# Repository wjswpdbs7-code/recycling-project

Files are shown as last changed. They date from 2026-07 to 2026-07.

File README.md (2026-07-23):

# ♻️ 가정용 분리수거 자동분류기 (Recycling Auto-Sorter)

> 쓰레기를 올리면 **AI가 판별하고 기계가 알아서 분류**하는 온디바이스 엣지 AI 시스템.
> HRD 직업훈련 최종 프로젝트 (12주) — YOLO11 · TensorRT · Jetson Nano · Raspberry Pi Pico 2 W

```
[투입] → 초음파 감지 → 3초 안정화 → C920 10프레임 촬영(1초)
      → TensorRT 판정(GPU 50ms/장) → ★10프레임 다수결★
      → 회전판 정렬(종이 0°/플라스틱 90°/비닐 180°) → 투입구 개방 → 낙하
      → 판별불가·비대상은 문을 열지 않고 리턴 (오분배 원천 차단)
```

## 핵심 수치

| 지표 | 값 |
|---|---|
| 학습 데이터 | AI Hub 생활폐기물 102,271장 / 17클래스 / 활용률 100% |
| 모델 | YOLO11n (2.6M 파라미터, 5.3MB) |
| 공식 Validation | mAP50 **0.912** (품목 병합 시 91~98%) |
| 학습 비용 | 약 **$10** (RunPod A40) |
| 엣지 추론 | **49.6ms/프레임** (Jetson Nano, TensorRT FP16) |
| 실물 테스트 | 오분배 **0건** (애매하면 리턴하는 안전 설계) |
| 자동 시작 | 전원 인가 → **약 40초 후 무인 가동** (systemd) |

## 시스템 구성

- **Jetson Nano** — 두뇌: C920 촬영, TensorRT 추론, 다수결 판정, 웹 모니터링(MJPEG)
- **Pico 2 W** — 손발: 초음파 감지·서보 2개(투입구/회전판)·LCD 상태표시, 상태머신 펌웨어(C)
- **노트북** — 개발·모니터링 전용 (분리해도 기계는 자립 동작)

## 저장소 구조

| 경로 | 내용 |
|---|---|
| `docs/` | **전체 문서** — 진행일지·설계서·클래스 설계·학습 보고서·배선 가이드·제작도·[포트폴리오 기록](docs/05_포트폴리오_기록.md) |
| `docs/img/` | 학습 곡선, confusion matrix, 실물 테스트 캡처, CAD 렌더, 성능 차트 |
| `models/` | 학습 완료 가중치 (.pt) + ONNX 변환본 |
| `training/` | AI Hub JSON→YOLO 변환기, 학습 결과 로그·곡선 (원본 데이터셋 20GB는 제외) |
| `inference/` | 판정·데모 코드 — Jetson 브리지, 노트북 브리지, 수집 도구, 스트리밍 |
| `pico_sonar_test/` | **최종 구동부 펌웨어** (상태머신: 감지→분배→재무장, LCD 자가복구) |
| `pico_*` | 개발 과정의 테스트·진단 펌웨어들 (초음파/LCD/서보 진단 도구 포함) |
| `cad/` | OpenSCAD 파라메트릭 3D 설계 (검증식 내장) |

## 문서 읽는 순서 (발표자료·기술서 제작용)

1. [`docs/05_포트폴리오_기록.md`](docs/05_포트폴리오_기록.md) — **의사결정 서사·시행착오·수치 총정리** (발표의 뼈대)
2. [`docs/00_진행일지.md`](docs/00_진행일지.md) — 일자별 타임라인
3. [`docs/03_학습_보고서.md`](docs/03_학습_보고서.md) — 학습 상세 + 실물 테스트 분석
4. [`docs/02_클래스_설계.md`](docs/02_클래스_설계.md) / [`docs/06_프로토타입_제작도.md`](docs/06_프로토타입_제작도.md) — 설계 근거

## 재현 방법 (요약)

```bash
# 1) 데이터: AI Hub 71385 실내형분류기 다운로드(국내 IP) 후 변환
python3 training/convert_aihub_to_yolo.py <이미지경로> <라벨경로> <출력> 17

# 2) 학습 (RunPod A40 기준)
yolo detect train model=yolo11n.pt data=data.yaml epochs=60 imgsz=640 batch=128 workers=8

# 3) Jetson 배포
yolo export model=best.pt format=onnx opset=12
/usr/src/tensorrt/bin/trtexec --onnx=best.onnx --saveEngine=runB17.engine --fp16

# 4) 실행 (Jetson): inference/jetson_bridge.py — systemd 서비스로 자동 시작
```

※ 데이터셋(20GB)·API 키(.env.local)는 저장소에 포함하지 않음.

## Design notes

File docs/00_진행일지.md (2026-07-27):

# 진행 일지 — 가정용 분리수거 자동분류기

> 목적: 사용자와 AI가 프로젝트 흐름을 빠르게 파악하기 위한 일자별 기록.
> 규칙: 의미 있는 작업·결정이 있을 때마다 그 날짜에 추가한다. 형식은 "한 일 / 결정 / 산출물" 3줄 구조를 기본으로.

---

## 2026-07-15 (화)

- **한 일**: 프로젝트 설계서 v0.1 작성 (6클래스, 캐러셀 방식, 저가형/표준형 티어). Pico 2 W + 서보 2개 + 버튼 테스트 (MicroPython)
- **결정**: 분배 기구는 회전 캐러셀 방식 채택
- **산출물**: `docs/01_설계서.md`(당시 루트), `servo_button_test.py`

## 2026-07-16 (수)

- **한 일**:
  - 서보+버튼 테스트를 C(Pico SDK)로 변환, WSL에 빌드 환경 구축(ARM 툴체인·SDK, sudo 없이) → `servo_button.uf2` 빌드 성공
  - 언어 전략 확정: Python(AI·서비스·대시보드) + C(MCU 실시간 제어)
  - 아파트 규모 논의 → 벌크 싱귤레이션은 선별장 영역, 투입구 제어(RVM 방식)가 정답. 처리량 계산
  - **클래스 4종 축소 결정** (비닐·종이 제외 → 경질 용기류만): 난이도가 "도전적→검증된 영역"으로
  - 데이터셋 조사(AI Hub 생활폐기물 71385 추천), 사용자가 받은 샘플 105장 분석 — 실내형분류기 파트가 우리 구도와 일치 확인
  - 학습 비용·시간 추정($10~20), 성능 목표 3층(모델/실기기/시스템) 정의
  - **RunPod 파이프라인 검증**: JSON→YOLO 변환기 작성, A40 팟에서 샘플 105장 스모크 학습(mAP50 0.911) 후 팟 종료 — 총 $0.11
  - 아파트 분리배출 규정 조사(투명페트 의무 등), YOLO 필요성 확정(검출=개수 검증 겸용), MCU/NPU 엣지 사양 조사(STM32N6 34FPS 실증), 혼합 쓰레기 싱귤레이터 기구 설계(클리트 컨베이어+리턴 루프, BOM 9~17만원)
- **결정**: 4클래스(투명페트/플라스틱/캔/유리) + 판별불가(비학습·후처리), YOLO11n, RunPod A40급, 실내형분류기 파트만 사용
- **산출물**: `servo_button_c/`, `training/convert_aihub_to_yolo.py`, `models`(스모크 테스트 결과는 `training/results_pipeline_test/`)

## 2026-07-17 (목)

- **한 일**:
  - AI Hub 공식 가이드라인 PDF(53쪽) 분석 → **29종 클래스 코드 공식 매핑표 확보** (페트=투명 무색만 확인)
  - aihubshell + API 키로 B2 파트(86MB) 테스트 다운로드 → 실측: B2는 93%가 오염 배치 → 오염 클래스 필요성 부상
  - 오염 라벨 기준 실물 확인(경계 애매성 발견), 데이터셋 분리 구조(품목×상태 매트릭스) 분석
  - **클래스 설계 탐구 → 9클래스(4품목+품목별오염4+other) 채택** — B2 실측 활용률 4%(4클래스) vs 100%(9클래스). `docs/02_클래스_설계.md` 작성
  - Run A 준비: A40 팟 생성 → **AI Hub 해외 IP 차단 발견** → 국내 로컬 다운로드(16GB) 후 rsync 업로드로 우회 (팟에 rsync 설치 필요했음)
  - 공식 Validation 실내형분류기 12,784장 로컬 확보·분포 분석 (학습 미사용, 최종 평가 전용 원칙 수립)
  - **Run A(4클래스 기준선) 학습 시작** — 실분포 확정: 39,643장/102,271장(38%). 중간 과적합 점검: 이상 없음
- **결정**: 9클래스 설계(당시), 평가는 공식 Validation + B폴더(조명)별 분해, Run B는 배치·worker 최적화 적용
- **산출물**: `docs/02_클래스_설계.md`, `training/aihub_download/`(Training 16GB + Validation 2GB), 변환기 모드 4/8/9

## 2026-07-18 (금)

- **한 일**:
  - **Run A 완료** (80ep, 5.2h): 공식 Validation **mAP50 0.985** (페트 0.991/플라스틱 0.962/캔 0.994/유리 0.991) — 전 클래스 목표(0.95) 통과, 과적합 없음
  - 모델 회수: `models/runA_yolo11n_4cls_best.pt`
  - **최종 클래스 17종으로 상향 확정** (아파트 규정 풀스펙: 클린9+오염8, other 소멸) — "학습은 17종, 추론 병합으로 5칸 시연" 구조. 9클래스 학습은 중복이라 생략
  - **Run B-17 학습 시작** — 1차 시도 OOM(컨테이너 RAM 한도 50GB, worker 24 과다) → worker 8로 재시작, 102,271장/60ep
  - **docs/ 폴더 신설·문서 대정리**: 설계서 v0.2 갱신(폐기된 6종 체계 등 구버전 내용 수정), 학습 보고서+그래프 작성, 인덱스·문서 규칙 수립, 본 진행일지 신설
  - 골판지 프로토타입 계획(서보2+DC1로 3분류 데모), 3D 모델링 방침(OpenSCAD 코드 CAD) 수립
- **결정**: E안 17클래스 최종 채택, 문서는 docs/에만 작성·구버전은 수정(중복 금지)
- **산출물**: `docs/` 전체 구조, `docs/03_학습_보고서.md`, 변환기 모드 17
- (오후) 웹캠 실물 테스트 환경 구축(`inference/watch_and_predict.py`, 촬영→즉시판정) —
  스프라이트병→플라스틱 오분류로 도메인 갭 실증. 복수 물체 카운트 동작 확인
- (오후) 3D 모델 v0.2→v1.0 재설계: 수직 낙하+캐러셀 정렬 방식 확정(깔때기 기각),
  과설계 제거(서보1 트랩도어·게이트/리턴 삭제), MDF 판재 구조, 검증 echo 내장(화각·낙하고·2L수용)
- **Run B-17 완료** (60ep, 총 ~7h·OOM 2회 극복): 공식 Validation 17클래스 mAP50 0.912.
  confusion matrix 분석 → 오류의 대부분이 "같은 품목 클린↔오염 혼동", 품목 병합 시 Run A급.
  **채택: Run B-17 단일 모델 + 품목병합 분배 + 오염 임계값 후처리.** 모델 회수·팟 종료(잔여 0)
- **비용 실적**: 전체 학습 캠페인 누적 약 $10 (예산 $10~20 내 완료)
- (저녁) 추론 데모를 Run B-17 + 채택 후처리(품목병합·오염임계·배출코칭)로 업그레이드 —
  Run A가 오인했던 종이컵을 정확 인식하며 복수 투입 판정 성공
- (저녁) **3D 모델 심층 개선 세션**: WSL 헤드리스 OpenSCAD 구축(AppImage) → AI가 렌더를
  직접 보며 평가-개선 3사이클. 렌더 검증으로 실결함 2건 발견·수정:
  ① 외닫이 트랩도어 개방 궤적이 수거함 관통(→ 양문 필수로 번복, 검증4 추가)
  ② 유리 낙하고 30mm vs 문짝 스윙 106mm 상충(→ 스테이지 +120mm로 양립)
  깔때기 목을 문열림 궤적 포함하게 재설계. 코드 내장 검증 4종 전부 통과.
  외장(디스플레이·투입구 베젤·회수도어·받침발)·기구 사실화(지지롤러·GT2벨트·경첩) 추가.
  렌더 3종 docs/img/cad_v11_*.png 보관
- (밤) **웹캠 실물 테스트 세션 2차** (사용자 직접, 12장, 검은 천 배경 채택): 투명 트레이→플라스틱 80% 정답,
  키친타올→종이 76% 배출 코칭 성공. 잘못된 수거함 분배 0건(애매 케이스 전원 판별불가행)

## 2026-07-19 (토)

- **한 일**: 분류테스트 12장 결과·원인 분석
  - 오류 3유형 확인: ① 검은 천 위 유령 검출(빈 배경에 glass 75% — 프레임 가장자리·어두운 주름 영역) ② 깨끗한 세제통→plastic_dirty 85%(그래픽 라벨을 오염으로 오인) + 투명 펌프캡→battery 59%(소형 원통 형태) ③ 물티슈(비닐)→paper 67%(연포장 인쇄면이 종이와 유사)
  - 근본 원인 3계층으로 정리: 도메인 갭(조명·블러·배경) / 경량 모델의 형태·색 프라이어 의존 / 후처리에 박스 위치·크기 검증 부재(유령 1개가 복수투입 오판으로 승격)
- (밤) 회색 무광 배경판으로 교체 후 추가 테스트 — 유령 박스 0건(배경 개선 효과 확인).
  단 **미학습 물체(OOD) 고신뢰 오분류 발견**: 딱풀→paper 75%(무광 원통+인쇄 라벨 프라이어),
  접착제 병→can 92%(스프레이캔 실루엣). 폐쇄형 검출기의 구조적 한계로 CONF_TH 안전망 무력화 —
  테스트 통틀어 첫 "잘못된 분배" 사례. 물티슈 팩도 paper 94%로 재오분류(검은 천 67%→회색 94%) —
  **환경 개선은 유령 검출은 제거하지만 학습 분포 밖 물체는 "더 확신 있게" 틀리게 함** →
  남은 오류는 환경이 아니라 데이터(fine-tuning)로만 해결 가능함을 실증
- **결정**: fine-tuning 촬영 목록에 그래픽 라벨 용기·물티슈류 연포장·소형 캡 필수 포함 + **비대상 물체(문구류 등)를 라벨 없는 네거티브 샘플로 추가**. 시연 물품은 학습 도메인(재활용 배출품)으로 구성. 데모 스크립트에 ROI+최소 박스 크기 필터 추가 예정
- **산출물**: 분류테스트/결과/ 판독 14건, `docs/03_학습_보고서.md` 실물 테스트 절 추가

## 2026-07-28 (월)

- **한 일**: **회고형 포트폴리오 PDF 제작** (HRD서류 폴더) — 성과 부각 대신 자체 피드백/아쉬운 점 중심 4페이지.
  구성: 요약(사실 수치만) → 유효했던 선택 5 → 아쉬운 점 5(모터 미검토/싱귤레이터 미착수/골판지·CAD 단절/
  파인튜닝 게이트 미달/분배 검증 미완 — 각각 "아쉬움→당시 상황→배운 것" 구조) → 트러블슈팅 6건 표 →
  후속 과제 6건(피드백과 1:1 대응, 진행 예정 명시). WeasyPrint(HTML→PDF)로 생성
- **이미지 중심 개정판**: 사용자 요청으로 `포트폴리오 모음/분리수거_자동분류기_포트폴리오.pdf`로 재제작 —
  docs/img 22종(실물 사진·회로도·학습곡선·혼동행렬·ft1 실물판정 7종 그리드·트러블슈팅 증상 사진·CAD)을
  각 절에 배치한 7페이지 판 (텍스트 서사는 동일, WeasyPrint)
- **산출물**: `포트폴리오 모음/분리수거_자동분류기_포트폴리오.pdf` (HRD서류 폴더 — repo 외부)

## 2026-07-27 (일)

- **한 일**: **발표자료 3차 수정본 작성** (HRD서류 폴더, 원본과 별도 저장) — 성과 강조형에서 **자체 평가형으로 전면 개편**.
  - 최종 목표를 "싱귤레이터(1개씩 분리) → 엣지 AI 판별 → 회전판 정렬 → 투입구 개방" 4단계로 명시하고,
    현재 구현 범위는 **3종 분류(서보 한계) + 투입구 카메라 엣지 분석까지**임을 개요부터 밝힘
  - 한계점 슬라이드 → **"자체 피드백 및 후속 과제"**로 개편: 기획 단계 하드웨어 선택 미흡(SG90 토크·가동각 미검토
    → 3칸 제한, 싱귤레이터 미착수, 골판지 수작업 개입) vs 유효했던 선택(17종 학습·병합, 파인튜닝+사전 게이트,
    엣지 TensorRT, 저비용 센서) 구분 + 후속 과제(싱귤레이터 설계 / 구동계 재선정 / MDF·3D프린트 재질 개선) 1:1 대응
  - **거짓 없는 수치·서사로 교정**: 실제 제작에 활용 못한 OpenSCAD CAD 강조 제거, 추론 속도를 채택 모델 기준
    51.5ms로 갱신, ft1 "게이트 0.892 미달(0.880) → 보류 → 실물 7/7 재검증 후 채택" 2단계 의사결정 명시
- **결정**: 발표 톤 = 좋았던 점/아쉬운 점/발전 방향 균형 서술, 성과 과시·미활용 작업 강조 배제
- **Wokwi 회로도 최종 설계 반영**: 구버전(`pico_sorter/wokwi`, 서보2개 4칸 v1)을 최종 펌웨어 위치
  `pico_sonar_test/wokwi/`로 이전·전면 갱신 — 서보1 도어 GP0(90/180)·서보2 회전판 GP1(0/90/180 3칸),
  HC-SR04 GP16/17(1k/2k 분압), LCD1602 I2C GP4/5, **서보 전원 별도(VCC 심볼)+GND 공통** 반영.
  main.py도 실물 C 상태머신(ARMED→SETTLING 3s→DETECT→WAITCMD→COOLDOWN)과 동일하게 재작성
- **프로젝트 기술서 작성**: 2차 기술서(hwp) 양식 구조를 그대로 재현해 최종 프로젝트 기술서 docx 생성
  (작성자 전제윤, 팀원 김도경·박시영 역할 분담 기재. 수행목표에 최종 4단계 목표 vs 현재 구현 범위 구분,
  상세 내용 5절: 본학습/파인튜닝·게이트/엣지 추론/기구 제어/한계·후속과제, 이미지 7종 삽입 — 회로도·학습곡선·혼동행렬·실물판정·시연)
- **발표문 작성 + 배경 서사 개편**: 슬라이드 1~11 발표문(약 10분) 작성. 이후 2·3번 슬라이드와 발표문을
  **편의성 중심 서사**(사람이 분류하지 않는 시스템을 아파트 단지 재활용장 단위로)로 재구성
- **산출물**: `발표자료_3차 수정본.pptx`, `발표문_1조_분리수거_자동분류기.docx`, `최종_1조_프로젝트_기술서_분리수거_자동분류기.docx` (HRD서류 폴더 — repo 외부),
  `pico_sonar_test/wokwi/{diagram.json,main.py}`

## 2026-07-24 (목)

- **한 일**:
  - **ft1 Jetson 배포 완료**: ONNX(opset12) 변환 → 전송 → TensorRT FP16 엔진 빌드(`runB17_ft1.engine`,
    추론 **51.5ms/프레임** — 기존 49.6ms와 동급) → `jetson_infer.py` 엔진 전환 → `sorter.service` 재시작.
    기동 확인: 엔진 로드·시리얼(/dev/ttyACM0)·웹모니터(8081) 정상. 기존 `runB17.engine`은 롤백용 보존
  - **웹모니터 영상 미표시 트러블슈팅**: 원인은 카메라가 아니라 **기동 순서** — 브리지 시작 시점에
    `/dev/video0` 미존재(uvcvideo가 13분 뒤 등록, dmesg로 확인) → 카메라 열기 1회 실패 후 그대로 운용,
    감지 시 프레임 0장으로 무조건 REJECT. 재시작으로 즉시 해결 + **자동 복구 패치**(열기 재시도 30회,
    운용 중 6초 연속 실패 시 재연결, 최종 실패 시 종료→systemd 재기동)
  - **ft1 실물 검증 7/7 전원 정답** (`docs/img/ft1_test_*.png`, 신뢰도 94~99%):
    종이뭉치 paper 98 / 종이컵 paper_pack 99 / **본드병 plastic 97(기존 can 92% 오분류 해결)** /
    돔뚜껑 pet 98 / 찌그러진 페트병 pet 94 / **투명 지퍼백 vinyl 97(기존 전 프레임 미검출 해결)** /
    검정 비닐 vinyl 98 — 자체 val 0.995가 실물에서 재현됨
- **결정**: **ft1 채택 확정** — 파인튜닝 목적(OOD 물체·투명 비닐 사각지대)이 실물로 입증됨.
  일반화 −3.2%p는 시연 범위에서 무영향
- **산출물**: `models/runB17_ft1_best.onnx`, Jetson `runB17_ft1.engine`, `inference/jetson_infer.py`(엔진 전환),
  `inference/jetson_bridge.py`(카메라 자동 복구), `docs/img/ft1_test_*` 7종

## 2026-07-22 (화) ~ 07-23 (수)

- **한 일**:
  - **골판지 프로토타입 기구 조립·캘리브레이션**: 투입구=서보1(물리핀1, 닫힘90°/열림180° 실측),
    회전판=서보2(물리핀2). FSR 검토 후 초음파로 회귀. 십자 프레임(팔 90° 간격) 제작
  - **3칸 분배 체계 확정**: 0°=종이(+종이팩) / 90°=플라스틱(+투명페트) / 180°=비닐, 그 외 REJECT 리턴.
    십자 프레임과 SG90 180° 한계에 정합 (SG90은 270° 불가 — 소프트웨어 아닌 내부 기구 한계)
  - **펌웨어 상태머신 완성** (`pico_sonar_test`): 감지→3초 안정화→DETECT→분석대기(초음파 무시)→
    SORT(회전판→문 개폐)→쿨다운→재무장. LCD 상태 표시 전체(READY/DETECTED/ANALYZING/RESULT/COMPLETE/리턴사유별)
  - **10프레임 다수결 판정 도입**: 1초간 10프레임 → 프레임별 판정 → 최다 득표 채택 (시간축 앙상블)
  - **노트북 브리지** (`bridge.py`, 8092): 브라우저 한 페이지에서 웹캠+Web Serial(COM5)+판정 —
    실시간 미리보기·프레임별 오버레이·감지 로그·C920 자동 선택
  - **fine-tuning 수집 도구** (`collect_data.py`, 8091): 숫자키=클래스, 위치는 모델 프리라벨(클래스무관
    최고신뢰 박스)·클래스는 사람 — 반자동 라벨링. 오버레이 미리보기·x키 실행취소
  - **Jetson 전자동 브리지 완성·검증** (`jetson_bridge.py`): DETECT→10프레임(GPU, 1초!)→다수결→SORT/REJECT.
    노트북 모니터링 웹(8081, MJPEG+로그) 내장. **REJECT 경로 실기 검증** (투명 지퍼백 → 전 프레임 미검출 →
    리턴 — 안전망 정상. 지퍼백은 비닐 fine-tuning 목록에 추가)
  - **모델 동일성 3중 검증**: ONNX md5 일치 / 17클래스 매핑 완전 동일 / 동일 이미지 교차추론 (can 0.479 vs 0.441,
    fp16 오차 정상 범위)
  - **systemd 자동 시작 등록·재부팅 실증**: 전원만 꽂으면 ~40초 후 분류기 자동 가동 (sorter.service, Restart=always)
  - 트러블슈팅: Jetson 시리얼 권한(dialout 그룹), 원격 pkill 자기종료 함정(브래킷 패턴), 발열 실측(부하 중 GPU 39°C)
  - **운용 조정**: 신뢰도 리턴 기준 0.50→**0.40** 완화(4개 판정 코드 일괄, 리턴율 개선 목적).
    LCD 개선 2건 — 대기화면에 **마지막 판정 결과 유지**(`LAST: PAPER`), 서보 노이즈로 인한 글자 깨짐에
    **자가 복구**(사이클 복귀·30초마다 재초기화). **Jetson에서 Pico 직접 굽기** 확립(부트로더 드라이브 원격 마운트 —
    케이블 이동 불필요). 모델 동일성 3중 검증(ONNX md5·매핑·교차추론), 노트북 분리 자립 운용 확인
  - **시연 영상 4편 확보** (`docs/img/demo_cycle_*.mp4`, 총 38초): 조립 완성체에서
    지퍼백·투명 컵뚜껑 투입 → LCD 상태 전환(DETECTED→ANALYZING) → 사이클 진행.
    PPT용 스틸컷 2장 추출(`demo_still_lcd_*.jpg`)
  - **시연용 fine-tuning 1차(ft1) 완료** (RunPod A40, 학습 ~10분):
    자체 수집 45장(시연 물체 5클래스, 반자동 라벨링)×15 오버샘플 525장 + AI Hub 서브샘플 10,952장,
    15에폭, lr0=0.0005(본학습의 1/10). numpy 2.x 비호환 크래시 1회(`pip install "numpy<2"`로 해결)
  - **ft1 평가 — 시연 특화 확인, 일반 성능은 소폭 하락**:
    자체 val(시연 물체 10장) mAP50 **0.995** / 공식 3,000장 게이트 mAP50 **0.880**
    (기존 0.912 대비 −3.2%p, 합격 기준 −2%p 미달). 하락 주도는 plastic(0.783)·오염 소수 클래스.
    시연 핵심(종이 0.962/비닐 0.913/투명페트 0.898)은 유지 → **시연 한정 배포 후보**로 보관
  - **모델·결과 회수 및 팟 종료**: `models/runB17_ft1_best.pt` 다운로드,
    학습 곡선·혼동행렬 `training/results_ft1/` + `docs/img/ft1_*` 보관, 팟 종료 확인(잔여 0)
- **결정**: 최종 구성 = Jetson(자동시작 브리지) + Pico(상태머신) + 노트북(모니터링만, 분리 가능).
  ft1은 게이트 미달로 **기본 채택 보류** — Jetson 배포 여부는 실물 재검증 후 결정(시연 물체 정확도 vs 일반화 트레이드오프)
- **산출물**: `pico_sonar_test/`(최종 펌웨어), `inference/bridge.py·collect_data.py·jetson_bridge.py`,
  Jetson `sorter.service`, `docs/06` v3 갱신, `models/runB17_ft1_best.pt`, `training/results_ft1/`,
  `docs/img/ft1_results_curves.png·ft1_confusion_matrix.png`

## 2026-07-21 (월)

- **한 일**:
  - **한 물체 다중 판정 버그 수정**: 스프라이트병에 `pet_transparent`·`plastic` 박스가 동시 생성.
    원인은 **NMS가 클래스별로 수행**되어 서로 다른 클래스 박스가 상호 제거되지 않은 것 →
    IoU 0.55 기준 **군집화 후 군집당 최고 신뢰도 1개만 대표**로 남기는 로직 추가.
    Jetson판·노트북판 양쪽 반영. 방치 시 "복수 투입" 오판을 유발하는 문제였음(세제통 사례와 동일 구조)
  - **일정상 범위 축소 결정 반영**: 싱귤레이터(클리트 컨베이어) 구현 제외,
    분류 4칸(품목 3종 + 기타)으로 축소, **오염 판정 보류**(오염 클래스를 같은 품목 클린으로 간주)
    → `jetson_infer.py` 상단에 `IGNORE_DIRTY`, `BIN_ITEMS` 설정으로 구현. **재학습 불필요**
- **결정**: 축소 운용안 채택 — 모델은 17종 그대로 두고 판정 계층만 단순화(설계 의도대로 활용).
  분배 품목 기본값 `pet / can / plastic`, 그 외 전부 기타함
- **산출물**: `inference/jetson_infer.py`(군집화+축소 설정), `inference/watch_and_predict.py`(군집화)

## 2026-07-20 (일)

- **한 일**:
  - 로컬 데이터셋 zip 40개 전량 해제·검증·삭제 (Training 해제본 19GB만 유지, Validation은 val_indoor와 중복 확인 후 zip 제거)
  - **HC-SR04 투입 감지 테스트 구축**: Pico 2 W C 펌웨어(`hcsr04_test/`, 3회 중앙값·히스테리시스·DETECT 이벤트) 빌드, Wokwi 시뮬레이션 파일 작성, 분압(1k/2k) 실배선
  - **원격 배선 진단 체계 확립**: PowerShell 경유로 노트북에서 COM5 시리얼 직접 읽기 + 부트로더 드라이브에 uf2 원격 굽기 성공. 진단 펌웨어(diag.c)로 판정 — 배선 전체 정상, "초음파 반사 미회수"만 남음(센서 방향 또는 VCC 확인 필요, 미해결)
  - **엣지 보드 확정: Jetson Nano Developer Kit** (보유 장비 활용, 구매비 0원) — Pi Zero 2 W 구매 계획 폐기. TensorRT fp16로 추론 0.03~0.05초 예상, C920 웹캠 USB 직결(도메인 일치 유지)
  - 최종 하드웨어 구성 확정: Jetson(촬영·추론·판정) + Pico 2 W(HC-SR04·SG90×2·LCD1602, USB 시리얼) + 서보 전원 분리(AA×4 또는 5V 어댑터)
  - Nano 배포 준비: **ONNX 변환 완료** (`models/runB17_yolo11n_17cls_best.onnx`, opset12 — JetPack 4.6 TensorRT 호환)
  - (밤) **Pico 하드웨어 3종 통합 검증 완료**:
    - 초음파 — 접촉 불량(점퍼 절연테이프 이음)이 원인이었음. 재배선 후 3cm~259cm 안정 측정
    - LCD1602 — I2C 무응답 → 4핀 재연결로 통신 성공 → 글자 깨짐 → **원인은 매핑이 아닌 초기화 타이밍 부족**
      (진단 펌웨어 `lcd_test.c`로 MAP A/B 6초 교대 표시하여 판별). 150us/6ms로 여유 확보 후 정상. 주소 0x27
    - 서보 2개 — 건전지 홀더(AA×4, 6V) 별도 레일 + GND 공통 배선 확립. `all` 명령으로 4종 일괄 점검 통과
    - 진단 도구 4종 작성: `diag.c`(초음파 3단) `i2cfind.c`(전핀 I2C) `pinfind.c`(외부 풀업) `lcd_test.c`(매핑)
  - **Jetson Nano 셋업 완료 (무모니터 원격)**: JetPack 4.6.1 굽기 → USB 시리얼 콘솔(COM6)로 초기 설정 전 과정
    원격 진행(라이선스·언어·계정 jetson/jetson1234·MAXN·DHCP) → SSH 키 주입 → 비밀번호 없는 원격 접속 확립.
    호스트명 jetson-nano, 시간대 Asia/Seoul, 랜선 인터넷 연결
  - **TensorRT FP16 엔진 변환 성공**: ONNX(11MB) → engine(9.3MB), **실측 49.6ms/프레임(초당 20장)**.
    노트북 CPU 대비 6~10배. C920 웹캠도 `/dev/video0`으로 인식 확인
  - **포트폴리오 체계 수립**: `docs/05_포트폴리오_기록.md` 신설(상세 서술형), `docs/img/`에 하드웨어·테스트·성능 이미지 축적 시작
- **결정**: 엣지 = Jetson Nano + TensorRT(확정, 실측 검증), 카메라 = C920 유지(fine-tuning 도메인 일관성),
  Pico는 센서·구동 전담, 전원 = 보드/서보 분리 원칙, **포트폴리오 자료는 상시 축적**(진행일지+상세기록+이미지 3종)
- **산출물**: `hcsr04_test/`, `pico_hw_test/`(진단 4종+통합테스트+sonar_lcd), `models/*.onnx`,
  Jetson `~/runB17.engine`, `docs/04_하드웨어_배선.md`, `docs/05_포트폴리오_기록.md`, `docs/img/` 8종 추가

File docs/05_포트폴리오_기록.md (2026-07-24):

# 포트폴리오·발표 기록 — 가정용 분리수거 자동분류기

> 목적: PPT 발표·포트폴리오에 그대로 옮겨 쓸 수 있는 **상세 서술** 기록.
> 진행일지([00_진행일지.md](00_진행일지.md))가 "언제 무엇을"이라면, 이 문서는 **"왜 그렇게 했고 어떻게 해결했는가"**.
> 최종 갱신 2026-07-20. 이미지는 `docs/img/`에 축적.

---

## 1. 프로젝트 한 줄 정의

> **혼합 투입된 가정 재활용 쓰레기를 카메라 1장으로 판별해 자동 분류하고, 애매하면 분류하지 않고 되돌려주는 온디바이스 AI 기기.**

핵심 차별점 세 가지:
1. **분류(classification)가 아닌 검출(detection)** — 복수 투입을 개수로 검증할 수 있어 "1개씩" 원칙을 소프트웨어가 보증
2. **"모르면 분류하지 않는다"는 안전 설계** — 오분류로 재활용 스트림을 오염시키느니 사용자에게 되돌려줌
3. **완전 오프라인 동작** — 클라우드 없이 3만~15만원대 엣지 보드에서 실시간 판정

---

## 2. 데이터셋과 클래스 설계 — 의사결정 서사

### 2.1 왜 AI Hub 생활폐기물(71385)인가
- 국내 제품군(라벨·용기 형태)이 그대로 담긴 유일한 대규모 공개 데이터 (총 551,562장)
- **"실내형 분류기" 파트(127,844장)가 우리 기기 구도와 정확히 일치** — 밀폐 조명 박스 안, 물체 1개, 고정 카메라
- 해외 데이터셋(TrashNet, TACO)은 제품군·클래스 체계가 달라 도메인 노이즈만 증가

### 2.2 클래스 설계가 3번 바뀐 과정 (포트폴리오 핵심 서사)

| 단계 | 설계 | 근거 | 폐기 이유 |
|---|---|---|---|
| 1차 | 6종 | 초기 직관 | 데이터셋 실제 라벨 체계와 불일치 |
| 2차 | **4종**(투명페트/플라스틱/캔/유리) | "어려운 품목 제외 → 검증된 영역으로" | **B2 파트 실측 결과 활용률 4%** — 93%가 오염 배치였음 |
| 3차 | 9종(4품목+오염4+기타) | 오염 클래스 필요성 확인 | 아파트 규정 풀스펙 대응 불가 |
| **최종** | **17종**(클린 9 + 품목별 오염 8) | 데이터 활용률 **100%**, 아파트 배출 규정 전 품목 커버 | — |

**핵심 인사이트**: 데이터를 실제로 내려받아 분포를 세어보기 전까지는 4클래스 설계가 합리적으로 보였다.
실측(B2 파트 86MB 샘플)에서 **활용률 4% vs 100%**라는 숫자가 나오면서 설계가 뒤집혔다.
→ *"가정이 아니라 측정이 설계를 결정한다"*

### 2.3 "학습은 세밀하게, 추론은 병합" 전략
17종으로 학습하되 **추론 시점에 품목 단위로 병합**한다:
- 분배: `pet + pet_dirty → 페트류` (수거함은 4칸이므로)
- 오염: dirty 신뢰도가 **0.70 이상일 때만** 오염 판정 (정밀도 우선)
- 비대상(종이·비닐·스티로폼·건전지): 분류하지 않고 **배출 코칭 안내**

이 구조 덕분에 "17종 학습의 세밀함"과 "5칸 기구의 단순함"을 동시에 얻었다.

---

## 3. 학습 — 과정과 결과

### 3.1 인프라·비용
- RunPod A40 48GB ($0.44/hr), 국내 IP 제한 우회를 위해 **로컬 다운로드(16GB) → rsync 업로드** 파이프라인 구성
- 총 비용 **약 $10** (파이프라인 검증 $0.11 + Run A $4 + Run B $5.5) — 당초 예산 $10~20 내

### 3.2 Run A (4클래스 기준선)
- 39,643장 / 80epoch / 5.2시간
- **공식 Validation mAP50 0.985** (페트 0.991 / 플라스틱 0.962 / 캔 0.994 / 유리 0.991)
- 자체 val 0.989 vs 공식 val 0.985 → 격차 0.4%p, **과적합 없음**

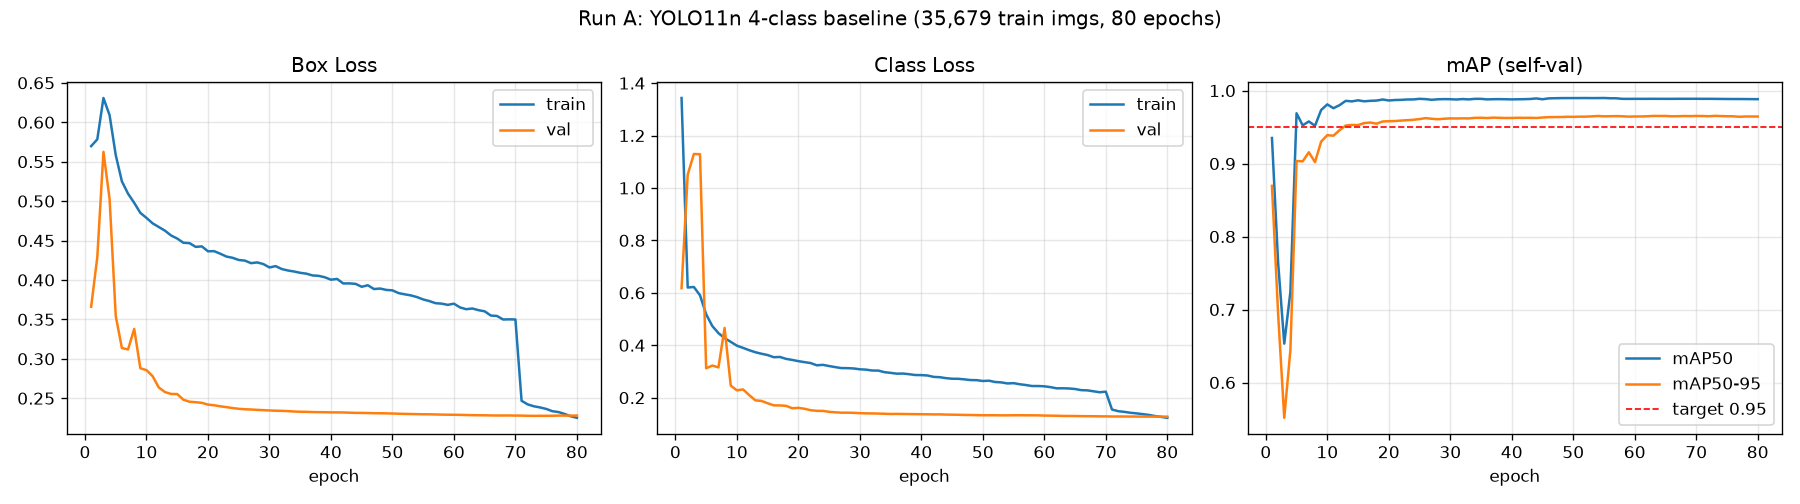
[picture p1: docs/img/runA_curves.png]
Run A curves


### 3.3 Run B-17 (최종 채택)
- 102,271장 전량 / 60epoch / 약 7시간
- **공식 Validation mAP50 0.912** (17클래스)

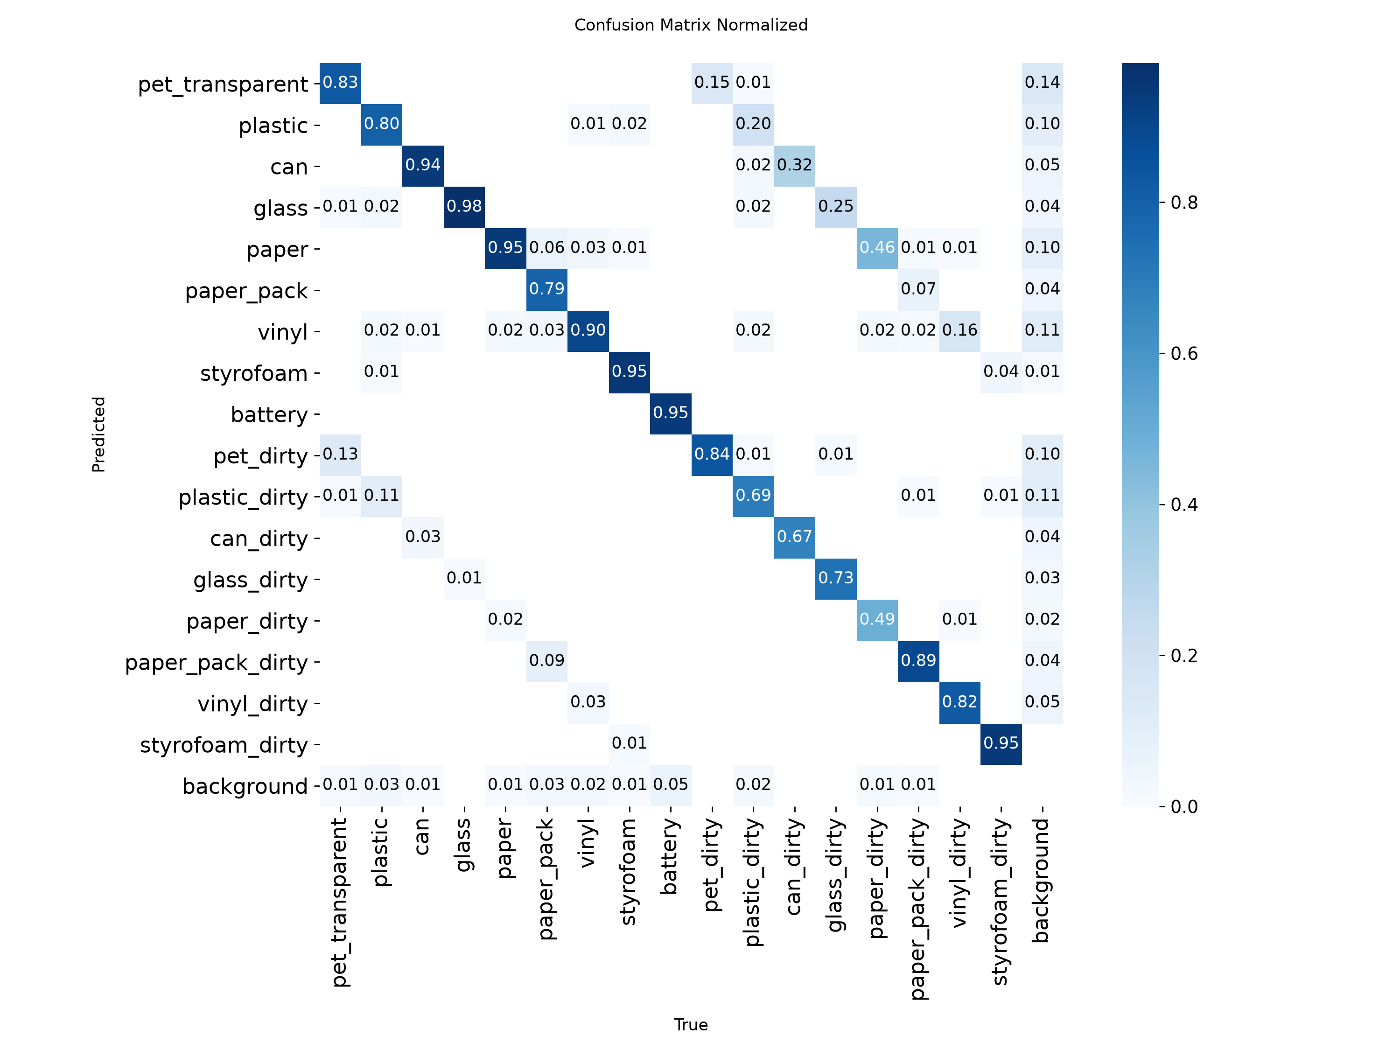
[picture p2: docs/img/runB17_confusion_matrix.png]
Run B-17 confusion matrix


**표면상 성능 하락(0.985 → 0.912)을 어떻게 해석했는가** — 발표에서 강조할 분석 대목:
- confusion matrix 분석 결과, 오류의 대부분이 **"같은 품목의 클린↔오염 혼동"**
  (pet 오류의 13%p가 pet_dirty행, plastic 오류의 11%p가 plastic_dirty행)
- **타 품목 오분류는 1~3%로 Run A와 동급**
- 품목 레벨 병합 시 정확도: 페트류 96% / 플라스틱류 91% / 캔류 97% / 유리류 98%
- → **결론: 모델을 다시 학습하지 않고, 후처리(병합+임계값)로 흡수**

*"숫자가 나빠 보일 때 원인을 분해하면, 재학습 대신 설계 변경이 답인 경우가 있다."*

### 3.4 운영 사고와 교훈
| 사고 | 원인 | 대응 | 교훈 |
|---|---|---|---|
| OOM 1차 | workers=24, 컨테이너 RAM 한도 50GB | workers=8 재시작 | 호스트 RAM(503GB) ≠ 컨테이너 한도 |
| OOM 2차 | 학습 후 자동 검증이 batch=128 상속 | 가중치는 무사, 평가만 batch=32로 별도 실행 | **학습·평가 배치를 분리 설정** |
| AI Hub 해외 IP 차단 | 502 에러 | 국내 로컬 다운로드 후 rsync 업로드 | 데이터 주권 제약을 파이프라인 설계에 반영 |

---

## 4. 실물 테스트 — 실패에서 얻은 것 (포트폴리오 하이라이트)

공식 Validation 0.912의 모델을 **웹캠으로 실제 생활용품에 적용**하자 전혀 다른 문제가 드러났다.

### 4.1 3유형의 오류와 근본 원인

| 사례 | 판정 | 원인 계층 |
|---|---|---|
| 검은 천 빈 배경 → `glass 75%` | 유령 검출 | **도메인 갭** — 천 주름의 세로 명암을 갈색 병 실루엣으로 오인 |
| 깨끗한 세제통 → `plastic_dirty 85%` | 오염 오판 | **프라이어 의존** — 파란 물결 그래픽 라벨을 오염 얼룩 패턴으로 |
| 투명 펌프캡 → `battery 59%` | 소형 물체 오인 | 17종 중 유일한 "소형 원통" 클래스로 수렴 |
| 물티슈(비닐) → `paper 94%` | 품목 혼동 | 학습된 vinyl은 투명 봉투 위주, 매트한 인쇄 연포장 미학습 |
| **플라스틱 본드 → `can 92%`** | **OOD 고신뢰 오분류** | **폐쇄형 검출기의 구조적 한계** |

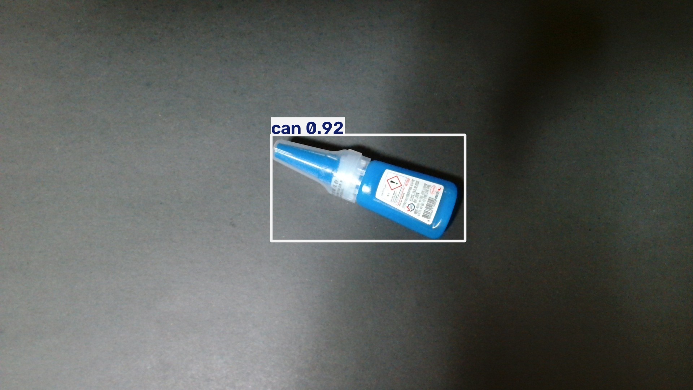
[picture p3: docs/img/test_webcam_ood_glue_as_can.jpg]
OOD 오분류

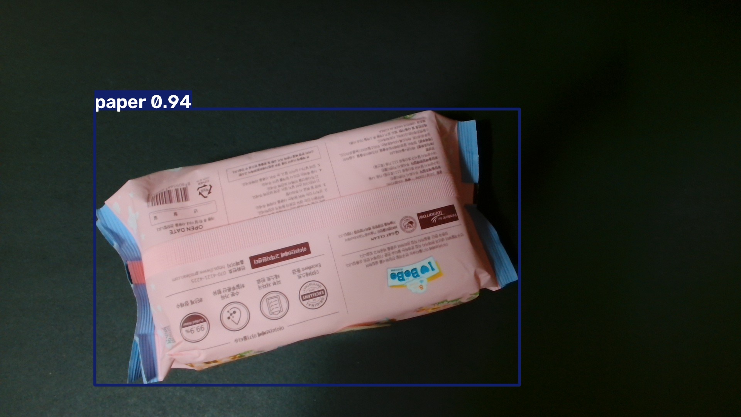
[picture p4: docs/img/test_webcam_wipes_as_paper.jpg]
물티슈 오분류


### 4.2 가장 중요한 발견 — 환경 개선이 오류를 "더 확신 있게" 만든다

검은 천 → 회색 무광 배경판으로 바꾸자:
- 유령 검출은 **0건으로 소멸** (환경 문제였음이 증명)
- 그러나 물티슈 오분류는 **67% → 94%로 확신이 오히려 상승**

> **결론: 환경 개선은 노이즈성 오류를 없애지만, 학습 분포 밖 물체(OOD)는 더 또렷하게 틀린다.**
> 남은 오류는 환경이 아니라 **데이터(fine-tuning)로만** 해결 가능하다.

이 실험이 fine-tuning 촬영 목록을 확정해 주었다:
그래픽 라벨 용기 / 물티슈류 연포장 / 소형 캡·뚜껑 / 투명 트레이 다각도 / **비대상 물체 네거티브 샘플**

### 4.3 안전망은 설계대로 작동했다
14장 테스트에서 **잘못된 수거함으로 분배된 사례 0건**.
애매한 케이스는 전부 신뢰도 임계값(0.50)에 걸려 "판별불가 → 리턴"으로 빠졌다.
→ *"정확도보다 중요한 것은 틀렸을 때의 동작이다."*

---

## 5. 엣지 배포 — 노트북에서 Jetson Nano로

### 5.1 보드 선정 과정
| 후보 | 판단 |
|---|---|
| Pico 2 W (RP2350) | ❌ RAM 520KB — 활성값조차 불가 |
| Pi Zero 2 W (3만원) | ⭕ 가능 (NCNN, 1~2초/프레임) — 저가 대안 |
| Luckfox/Milk-V (NPU 0.5TOPS) | △ int8 변환 필수, 개발 비용 큼 |
| **Jetson Nano (보유)** | ✅ **채택** — GPU+TensorRT, 구매비 0원 |

### 5.2 배포 파이프라인
```
runB17_best.pt (PyTorch)
   → ONNX opset12 (노트북에서 변환, 11MB)
   → TensorRT FP16 engine (Jetson에서 빌드, 9.3MB)
```

### 5.3 실측 성능 (2026-07-20)
```
&&&& PASSED TensorRT.trtexec
GPU Compute Time : 49.0 ms
H2D / D2H        : 0.47 / 0.08 ms
End-to-End       : 49.6 ms  (초당 약 20장)
```

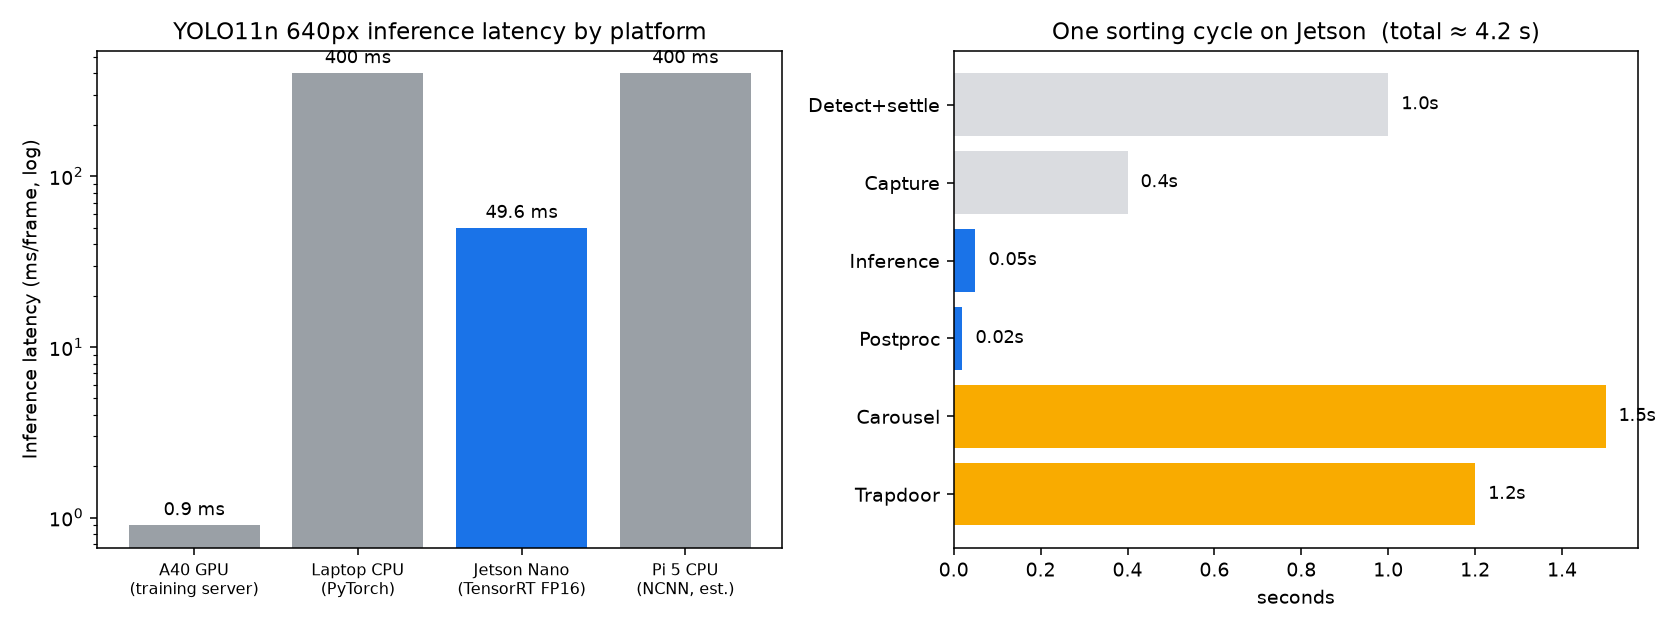
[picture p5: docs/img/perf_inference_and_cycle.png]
성능 비교


**해석**: 노트북 CPU(0.3~0.5초) 대비 **6~10배 향상**. 사이클 예산 8초에서 추론 비중이 0.6%로 축소되어,
**병목이 AI가 아니라 기구(캐러셀 회전·도어 개폐)로 이동**했다.
→ 발표 포인트: *"AI 최적화가 끝나는 지점에서 기계 설계가 시작된다."*

### 5.4 무모니터 원격 셋업 (기술적 성과)
모니터·키보드 없이 **USB 시리얼 콘솔(ttyGS0)만으로** JetPack 초기 설정을 완료:
라이선스 → 언어/지역 → 계정 생성 → 파티션 → 전력 모드(MAXN) → 네트워크
이후 SSH 키를 시리얼로 주입해 **비밀번호 없는 원격 개발 환경** 구축.

---

## 6. 하드웨어 프로토타입 — 시행착오 기록

### 6.1 구성
| 장치 | 역할 | 핀 |
|---|---|---|
| HC-SR04 | 투입 감지 | TRIG=GP16, ECHO=GP17(1k/2k 분압) |
| LCD1602 I2C | 판정 결과 표시 | SDA=GP4, SCL=GP5 |
| SG90 ×2 | 투입구·분배 구동 | GP0, GP1 (전원 분리) |

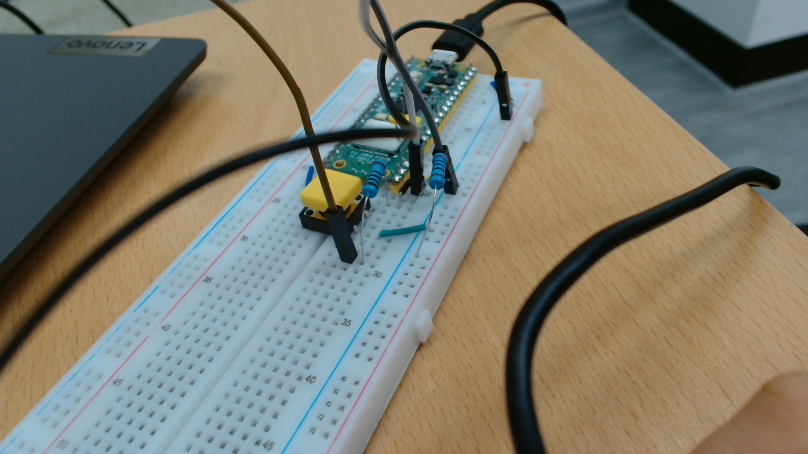
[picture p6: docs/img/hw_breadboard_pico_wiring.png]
브레드보드 배선


### 6.2 해결한 문제 3건

**① 초음파 "에코 없음" (수 시간 소요)**
- 증상: 측정 실패만 반복
- 진단: **전용 진단 펌웨어를 작성**해 ⓐ내부 풀업 테스트로 분압 연결 확인 ⓑ평상시 레벨 ⓒ트리거 응답을 분리 측정
- 원인: 배선은 정상, **점퍼선을 절연테이프로 맞댄 이음의 접촉 불량**
- 교훈: **테이프 접합 금지, 브레드보드 빈 줄을 중계점으로 사용**

**② LCD 통신 실패 → 글자 깨짐**
- 1단계: I2C 스캔 무응답 → **전 핀쌍 자동 탐색 펌웨어** 작성해 배선 문제 배제
- 2단계: 4가닥 재연결 후 통신 성공, 그러나 글자 깨짐
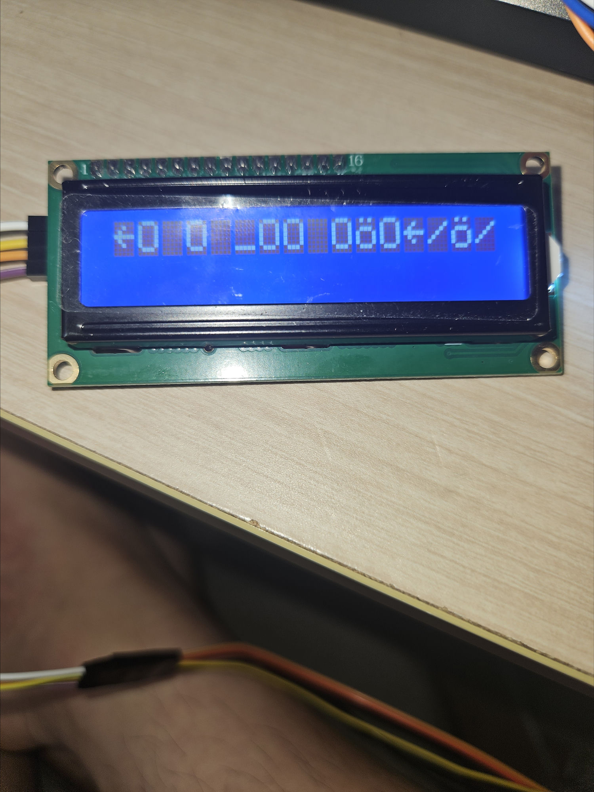
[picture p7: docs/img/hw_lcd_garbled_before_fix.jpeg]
깨진 화면
  
- 3단계: **매핑 A/B를 6초씩 번갈아 표시하는 진단 펌웨어**로 원인 특정
- 원인: 핀 매핑이 아니라 **초기화 타이밍 부족** → 나이블당 150µs, 초기화 6ms로 여유 확보
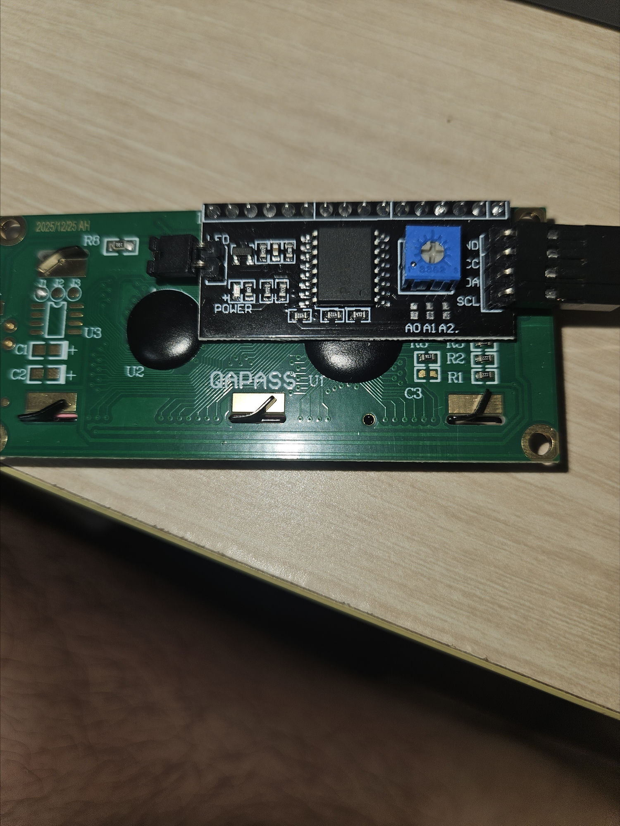
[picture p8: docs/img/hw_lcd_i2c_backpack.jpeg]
I2C 백팩
  

**③ 전원 설계**
- 규칙 확립: **빨간 레일 분리(USB 5V / 건전지 6V), 파란 레일(GND) 전부 공통**
- 근거: SG90 2개 스톨 시 1.4A — USB 한계(0.5~0.9A) 초과 → 보드 리셋

### 6.3 방법론적 성과
문제마다 **일회용 진단 펌웨어를 작성해 가설을 하나씩 배제**하는 방식을 사용했다.
(`diag.c` 초음파 3단 검사 / `i2cfind.c` 전핀 탐색 / `pinfind.c` 외부 풀업 감지 / `lcd_test.c` 매핑 A/B 비교)
→ 발표 포인트: *"추측 대신 측정 도구를 만들어 원인을 좁혔다."*

---

## 7. 3D 설계 — 코드 CAD와 자가 검증

OpenSCAD로 파라메트릭 설계 후, **헤드리스 렌더링으로 AI가 직접 결과를 보며 평가-개선을 반복**했다.

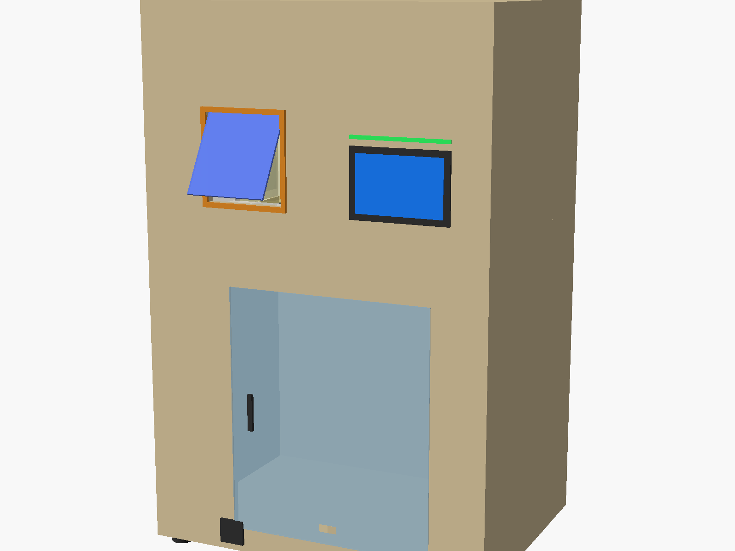
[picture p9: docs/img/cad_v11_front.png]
CAD 정면

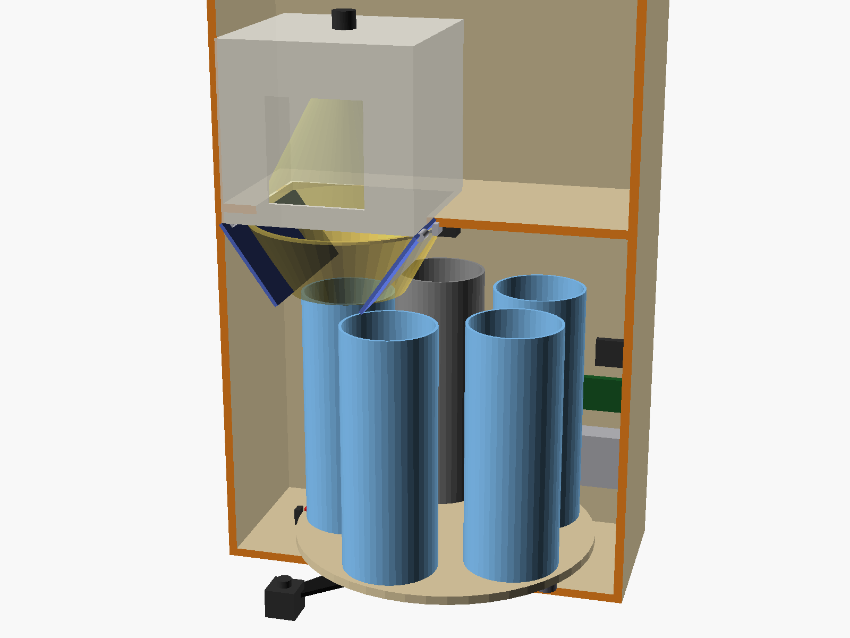
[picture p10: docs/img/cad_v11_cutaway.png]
CAD 단면


렌더 검증으로 발견한 실제 결함 2건:
1. **외닫이 트랩도어의 개방 궤적이 수거함을 관통** → 양문식이 기하학적으로 필수임을 확인(초기 "단순화" 판단을 번복)
2. **유리 낙하고 30mm vs 문짝 스윙 106mm 상충** → 스테이지를 +120mm 올려 양립

코드에 **검증식 4종을 내장**(카메라 화각 61°<66°, 낙하고, 2L 페트 수용, 도어 스윙 간섭)해 파라미터 변경 시 자동 확인.

---

## 7-1. 범위 축소와 "설계가 값을 한 순간" (2026-07-21)

12주 일정 현실화를 위해 구현 범위를 줄였다: **싱귤레이터 제외 / 분류 4칸(품목 3 + 기타) / 오염 판정 보류**.

주목할 점은 **이 축소에 재학습이 전혀 필요 없었다**는 것이다.
"학습은 17종으로 세밀하게, 추론에서 병합" 구조를 처음부터 택했기 때문에, 설정 두 줄로 끝났다:

```python
IGNORE_DIRTY = True                    # 오염 클래스를 같은 품목 클린으로 간주
BIN_ITEMS = ["pet", "can", "plastic"]  # 나머지는 전부 '기타'함
```

| 입력 | 축소 전 | 축소 후 |
|---|---|---|
| `plastic_dirty 85%` | 판별불가 + "세척 후 배출" | **플라스틱함으로 분배** |
| `glass 92%` | 유리함 분배 | 기타함 |
| `paper 88%` | 판별불가 + 배출 코칭 | 기타함 |

→ 발표 포인트: *"모델을 다시 학습하지 않고 운용 정책만 바꿔 요구사항 변경에 대응했다.
17종 학습은 지금은 과잉으로 보이지만, 나중에 오염 판정·품목 확장을 켜는 순간 그대로 되살아난다."*

### 함께 수정한 버그 — 한 물체 다중 판정
투명 페트병 하나에 `pet_transparent`와 `plastic` 박스가 동시에 잡히는 현상 발견.
원인은 **YOLO의 NMS가 클래스별로 동작**해 서로 다른 클래스의 겹친 박스를 제거하지 못하는 것.
방치하면 "서로 다른 품목 2개 = 복수 투입" 규칙에 걸려 **물체 1개를 리턴하는 오판**이 발생한다.
→ **IoU 0.55 군집화**로 겹친 박스를 한 물체로 묶고 최고 신뢰도 클래스만 대표로 채택.
(같은 원인의 과거 사례: 세제통 본체 `plastic_dirty` + 캡 `battery` → 복수 투입 오판)

## 7-2. 전자동 사이클 완성 (2026-07-22~23) — 시스템 통합의 장

이틀간 골판지 프로토타입 조립과 소프트웨어 통합으로 **전원만 꽂으면 도는 완전 자동 분류기**가 완성됐다.

### 최종 아키텍처

```
[쓰레기 투입]
   → Pico: 초음파 감지 → 3초 안정화(손 빼는 시간) → "DETECT"
   → Jetson: C920로 1초간 10프레임 촬영 → TensorRT 프레임별 판정(GPU, 총 ~1초)
   → ★ 다수결(최다 득표 판정 채택) ★ → "SORT PAPER|PLASTIC|VINYL" 또는 "REJECT"
   → Pico: 회전판 정렬(0/90/180°) → 투입구 개방(90→180°) → 닫힘 → LCD "LAST: ○○"
   → 2초 쿨다운 → 재무장 (사이클 중에는 초음파 무시)
```

### 핵심 설계 결정과 근거

1. **10프레임 다수결 (시간축 앙상블)** — 단일 프레임의 우연한 오판(유령 박스·순간 반사·신뢰도 출렁임
   34%↔80% 실측)이 소수표로 묻힌다. GPU 추론 50ms 덕분에 10장 분석이 1초 — Nano에서만 가능한 설계.
2. **상태머신으로 초음파 게이팅** — 분석·분배 중 초음파를 완전히 무시해 문짝·회전판 움직임의 오감지 차단.
   REJECT 시엔 문을 열지 않아 물체가 사용자에게 돌아감 (오분배 원천 차단 유지).
3. **3칸(0/90/180°) 확정** — SG90의 180° 물리 한계(내부 포텐셔미터·스토퍼)와 십자 프레임(팔 90°)의
   기하학적 정합. "각도를 270°까지 소프트웨어로?"라는 질문에 대한 답: **한계는 코드가 아니라 기구에 있다.**
4. **systemd 자동 시작** — `sudo reboot` 실증: 전원 인가 후 약 40초 만에 무인 가동 (Restart=always 자가복구 포함).

### 통합 과정의 실전 문제 해결 (발표 소재)

| 문제 | 진단 | 해결 |
|---|---|---|
| Jetson에서 Pico 시리얼 EACCES | 계정이 dialout 그룹에 없음 | usermod + 재로그인 세션 |
| 원격 재시작 명령이 자꾸 무응답 | `pkill -f`가 명령 자신을 매치해 자기 종료 | 브래킷 패턴 `"jetson_bridg[e]"` |
| LCD가 사이클 후 깨짐 | 서보 구동 노이즈가 I2C 나이블 오염 | 사이클 복귀·30초마다 재초기화(자가 복구) |
| 재부팅 후 카메라 소실 | USB 헐거움 | 실기기 조립 시 케이블 고정 반영 |
| 펌웨어 굽기마다 케이블 이동 | — | Jetson에서 부트로더 드라이브 원격 마운트로 직접 굽기 |

### 시연 영상 (2026-07-23)

조립 완성체 실동작 영상 — `docs/img/demo_cycle_1~4*.mp4` (LCD 상태 전환과 기구 동작 포함).
PPT 삽입용 스틸: `demo_still_lcd_detected.jpg`(감지 3초 대기), `demo_still_lcd_analyzing.jpg`(분석 중).

### 실기 검증 기록

- **REJECT 경로 실증**: 투명 지퍼백 → 10프레임 전부 미검출 → 리턴. 안전망 정상 + "투명·평면 비닐"이
  모델 사각지대임을 재확인 (fine-tuning 1순위 근거)
- **모델 동일성 3중 검증**: ONNX md5 일치 / 17클래스→그룹 매핑 완전 동일 / 동일 이미지 교차 추론
  (PyTorch fp32 can 0.479 vs TensorRT fp16 can 0.441 — 변환 오차 정상 범위)
- **발열**: 상시 추론 부하에서 GPU 39°C (스로틀링 한계 97°C 대비 여유 — 방열판만으로 충분)
- **운용 파라미터**: 신뢰도 리턴 기준 0.40 (0.50에서 완화 — 다수결 도입으로 프레임 단위 오차 흡수력이
  생겨 낮출 여지 확보), 감지 15cm/해제 18cm 히스테리시스

---

## 7-3. 시연용 fine-tuning 1차 (2026-07-23) — 특화와 일반화의 트레이드오프

일정상 대규모 재수집(400장+) 대신 **시연 물체 한정 소량 fine-tuning**을 먼저 실험했다.
"내 시연 물체는 확실히 잡되, 기존 일반 성능을 얼마나 잃는가"를 수치로 확인하는 것이 목적.

### 설계

| 항목 | 값 | 근거 |
|---|---|---|
| 자체 데이터 | 45장 (5클래스: 투명페트 11/종이팩 10/종이 8/플라스틱 8/비닐 8) | 반자동 라벨링 도구(`collect_data.py`)로 실배치 환경에서 수집 |
| 오버샘플 | ×15 → 525장 | 소량 데이터의 학습 기여도 확보 |
| 망각 방지 | AI Hub 서브샘플 10,952장 혼합 (총 11,477장) | 파국적 망각(catastrophic forgetting) 완화 |
| 학습 | 15에폭, lr0=0.0005 (본학습의 1/10), A40 약 10분 | 기존 가중치 미세 조정만 |
| 합격 게이트 | 공식 3,000장 mAP50 ≥ 0.892 (기존 0.912 − 2%p) | 일반 성능 하락 허용 한도를 사전에 정의 |

### 결과 — 게이트 미달, 그러나 목적은 달성

- 자체 val(시연 물체 10장): **mAP50 0.995** — 시연 물체 특화 목적 달성
- 공식 게이트(3,000장): **mAP50 0.880** — 기준 0.892에 1.2%p 미달 (기존 대비 −3.2%p)
- 하락 주도: plastic 0.783, 오염 소수 클래스(can_dirty 0.728, paper_dirty 0.670).
  **시연 핵심 클래스는 유지**: paper 0.962 / vinyl 0.913 / pet_transparent 0.898 / styrofoam 0.967
- 학습 곡선·혼동행렬: `docs/img/ft1_results_curves.png`, `ft1_confusion_matrix.png`

### 판단 (발표 소재 — "합격 기준을 사전에 정의하고, 미달이면 자동 채택하지 않는다")

ft1은 게이트 미달로 **일단 채택 보류**하고, 최종 판단을 실물 재검증으로 넘겼다.
사전 정의한 게이트가 없었다면 자체 val 0.995만 보고 무조건 배포했을 것 — 평가 체계가 과적합 배포를 막았다.
과정 중 트러블슈팅: RunPod numpy 2.x·torch 2.1 비호환 크래시 → `numpy<2` 고정으로 해결. 팟은 회수 즉시 종료(잔여 0).

### 실물 재검증 → 채택 확정 (2026-07-24)

Jetson에 TensorRT FP16으로 배포(51.5ms/프레임, 기존과 동급) 후 기존 실패 사례를 포함한
실물 7종을 투입 — **7/7 전원 정답, 신뢰도 94~99%** (`docs/img/ft1_test_*.png`):

| 물체 | ft1 판정 | 비고 |
|---|---|---|
| 구겨진 종이 뭉치 | paper 98% | |
| 종이컵 | paper_pack 99% | 종이 병합 규칙 정상 |
| **본드병(록타이트)** | **plastic 97%** | **기존 can 92% 오분류 → 해결** |
| 투명 돔뚜껑 | pet_transparent 98% | |
| 찌그러진 투명 페트병 | pet_transparent 94% | 변형 내성 확인 |
| **투명 지퍼백** | **vinyl 97%** | **기존 전 프레임 미검출(사각지대) → 해결** |
| 검정 비닐 | vinyl 98% | 저대비 배경에서도 인식 |

**결론: ft1 채택 확정.** 45장의 표적 데이터만으로 OOD 오분류와 투명 비닐 사각지대를 동시에 해결했고,
일반화 손실(−3.2%p)은 시연 범위(3칸 판정)에서 영향이 없음을 실물로 입증했다.
"게이트 미달 → 보류 → 실물 검증으로 최종 판단"의 2단계 의사결정 자체가 발표 스토리가 된다.

같은 날 트러블슈팅 1건: 웹모니터 영상 미표시 — 원인은 브리지 기동 시점에 `/dev/video0` 미존재
(카메라 늦은 인식, dmesg로 확인). 열기 재시도 30회 + 운용 중 재연결 + 실패 시 systemd 재기동 유도로
**카메라 자동 복구 체계**를 추가해 재발을 차단했다.

## 8. 현재 상태와 남은 과제 (2026-07-23 기준)

### 완료
- [x] 데이터셋 분석·변환 파이프라인 (17클래스, 활용률 100%)
- [x] Run A / Run B-17 학습 및 채택 결정
- [x] 채택 후처리(병합·임계값·코칭) 구현 및 실물 검증
- [x] 웹캠 실물 테스트 → 오류 유형 분석 → fine-tuning 목록 확정
- [x] Jetson Nano 셋업 + TensorRT FP16 변환 (49.6ms 실측)
- [x] Pico 하드웨어 검증 (초음파·LCD·서보) + 진단 펌웨어 방법론
- [x] 골판지 프로토타입 조립·캘리브레이션 (투입구 90/180°, 회전판 3칸)
- [x] **전자동 사이클 완성** — 감지→10프레임 다수결→분배, systemd 자동 시작, 노트북 분리 자립 운용
- [x] fine-tuning 수집 도구 (반자동 라벨링: 위치=모델, 클래스=사람)
- [x] 시연용 fine-tuning 1차(ft1) — 학습·게이트 평가·모델 회수·팟 종료 (자체 0.995 / 공식 0.880)
- [x] **ft1 Jetson 배포·실물 검증 7/7 → 채택 확정** (본드병·투명 지퍼백 기존 실패 해결, 51.5ms)
- [x] 카메라 자동 복구 체계 (늦은 인식/탈락 시 재시도·재연결·systemd 재기동)
- [x] 3D 모델 v1.1 (검증식 내장)

### 남은 과제
- [ ] SORT 3경로 실물 분배 정밀 검증 (봉투 정렬 각도 보정)
- [ ] 발표자료·기술서 제작 (본 레포 기반)
- [ ] (여유 시) MDF 실기기, 서보 승급(MG996R), 종료 버튼

---

## 9. 발표용 수치 요약 (암기용)

| 지표 | 값 |
|---|---|
| 학습 데이터 | 102,271장 / 17클래스 / 활용률 100% |
| 모델 | YOLO11n, 2.6M 파라미터, 5.3MB |
| 공식 Validation | mAP50 **0.912** (품목 병합 시 96~98%) |
| 학습 비용 | 약 **$10** (A40 12시간) |
| 엣지 추론 | **49.6ms/프레임** (Jetson Nano TensorRT FP16) |
| 예상 사이클 | **약 4.2초** (추론 0.05초, 나머지는 기구) |
| 실물 테스트 | 14장 중 오분배 **0건** (안전망 작동) |
| 시연 특화 ft1 | 자체 val **0.995** / 공식 0.880 → **실물 7/7 검증 후 채택** |
| ft1 실물 검증 | **7/7 정답** (신뢰도 94~99%, 기존 실패 2종 해결) |

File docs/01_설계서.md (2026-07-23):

# 가정용 분리수거 자동분류기 설계서

> 버전 0.2 (2026-07-18) — 클래스 체계·AI 모델·데이터셋을 확정 내용으로 갱신 (2장, 4장).
> 버전 0.1 (2026-07-15) — 최초 설계. 예산 티어별(저가형 / 표준형) 병행 설계.
>
> 관련 문서: [02_클래스_설계.md](02_클래스_설계.md) (클래스 확정 근거) · [03_학습_보고서.md](03_학습_보고서.md) (학습 결과)

---

## 1. 프로젝트 개요

### 1.1 목표
가정에서 발생하는 재활용 쓰레기를 투입구에 넣으면 **비전 AI가 품목을 인식하고, 기구부가 해당 수거함으로 자동 분배**하는 탁상~스탠드형 시제품을 제작한다.

### 1.2 핵심 가치
- 분리배출 오류율 감소 (특히 투명 페트 별도 배출 등 헷갈리는 규정 자동 처리)
- 배출 통계 대시보드 제공 (품목별 배출량, 재활용 기여도)
- AI(비전 분류) + 임베디드 제어 + 웹 대시보드를 아우르는 풀스택 포트폴리오

### 1.3 성공 기준 (시연 기준)
| 항목 | 목표치 |
|---|---|
| 분류 정확도 (시연 품목) | ≥ 90% |
| 1개 처리 시간 (투입→수거함 도달) | ≤ 8초 |
| 연속 처리 | 10개 연속 무고장 |
| 대시보드 | 실시간 분류 이력·통계 표시 |

---

## 2. 분류 품목 (v0.2 확정 — 학습 17종 / 시연 분배 4+1)

초기안(6종+예외)은 검토 결과 폐기하고, **"학습은 세밀하게(17종), 분배는 기구에 맞게(4품목+판별불가)"** 2계층 구조로 확정했다. 근거와 매핑 상세는 [02_클래스_설계.md](02_클래스_설계.md).

**시연 기기 분배 (수거함 5칸):**

| 수거함 | 대상 | 보조 검증 |
|---|---|---|
| 투명 페트 | 무색 투명 생수·음료병 (라벨·뚜껑 부착 포함) | 로드셀(가벼움) |
| 일반 플라스틱 | 유색 페트, PP/PE 용기 | |
| 캔 | 알루미늄·철 캔 | 유도형 금속센서 |
| 유리 | 유리병 (전 색상) | 로드셀(무거움) |
| 판별불가 | 오염 8종·비대상 품목(종이·비닐 등)·저신뢰·복수투입 | 품목명 안내(배출 코칭) 표시 |

**학습 클래스 (17종, 아파트 규정 풀스펙):** 클린 9종(4품목 + 종이·종이팩·비닐·스티로폼·건전지) + 품목별 오염 8종. 아파트형(수거함 9~10칸) 확장 시 재학습 없이 병합 규칙만 변경.

> **설계 원칙(유지):** 신뢰도(confidence)가 임계값 미만이면 억지로 분류하지 않고 "판별불가" 칸으로 보낸다. 시연 중 오분류로 인한 신뢰 하락을 막는 안전장치이자, 실제 제품에서도 합리적인 UX. 비닐·종이를 "분배"하지 않는 이유는 기구 걸림·투입구 규격 문제이며, "인식"은 17종 학습으로 수행해 안내 메시지에 활용한다.

---

## 3. 시스템 아키텍처

```
[투입구+도어]                                      [웹 대시보드]
     │                                                  ▲
     ▼                                                  │ (Supabase Realtime)
[촬영 스테이지] ──이미지──▶ [AI 추론부] ──클래스──▶ [제어부(MCU)]
 (조명 박스,               (YOLO/CNN)       │        │
  IR 투입감지,                              │        ▼
  로드셀·금속센서*)                          │   [분배 기구부]
                                            │    회전 캐러셀 + 배출 도어
                                            ▼        │
                                      [DB: 분류 이력] ▼
                                              [수거함 ×6 + 판별불가함]
```

### 3.1 처리 흐름 (상태 머신)
1. **IDLE** — 대기. IR 센서가 투입 감지하면 →
2. **CAPTURE** — 도어 잠금, 조명 ON, 카메라 촬영 (2~3장, 각도/노출 다르게)
3. **INFER** — AI 추론. (보조: 금속센서로 캔 여부 교차검증, 로드셀로 무게 기록)
4. **SORT** — 캐러셀을 해당 수거함 위치로 회전 → 바닥 도어 개방 → 낙하
5. **LOG** — 결과를 로컬 DB + Supabase에 기록, 대시보드 실시간 갱신
6. **RESET** — 원위치 복귀 → IDLE. 오류 시 **ERROR** 상태(부저+LED, 대시보드 알림)

### 3.2 분배 기구 방식 선정

6분류는 플리퍼(차단판) 방식으로는 기구가 5개 이상 필요해 복잡도가 폭증한다. **회전 캐러셀 방식을 채택**한다.

| 방식 | 구조 | 6분류 적합성 | 판정 |
|---|---|---|---|
| **회전 캐러셀 (채택)** | 촬영 스테이지 바닥이 열리고, 그 아래 수거함 6+1개가 원형 배치된 턴테이블이 회전해 정렬 | 모터 1개(스텝모터)로 N분류 확장 가능. 기구 최단순 | ✅ |
| 회전 슈트 | 낙하 슈트가 회전해 고정 수거함으로 유도 | 가능하나 슈트 길이만큼 높이 증가, 비닐·종이가 슈트에 걸림 | △ |
| 컨베이어 + 플리퍼 | 벨트 위 이송 중 클래스별 차단판이 쳐냄 | 산업 표준이나 6분류엔 플리퍼 5개+벨트 → 비용·고장점 최다 | ✖ |

**캐러셀 상세:**
- 스텝모터(NEMA17) + 감속(GT2 벨트 or 3D프린팅 기어) → 턴테이블 회전
- 원점 검출: 홀센서 or 리미트 스위치 1개 (전원 인가 시 호밍)
- 촬영 스테이지 바닥: 서보(MG996R) 2개로 여닫는 양문형 트랩도어
- 유리 파손 방지: 낙하 높이 ≤ 15cm + 수거함 바닥 EVA 폼

---

## 4. AI 설계

### 4.1 모델 (v0.2 확정: YOLO11n)
- **확정: YOLO11n (detection)** — 물체 위치+클래스 동시 획득 + **복수 투입 감지(박스 수)·빈 스테이지 확인**이 필수 기능이라 classification 단독으로는 불가.
  Run A 실증: 공식 검증셋 mAP50 0.985 ([03_학습_보고서.md](03_학습_보고서.md)) — n(nano)으로 충분함 확인
- 승급 게이트: 클린 mAP50 < 0.95 또는 페트↔유리 혼동 발생 시에만 YOLO11s 비교 실험
- (기각된 대안 기록) MobileNet류 classification — 물체 1개 보장을 모델이 검증할 수 없어 기각. crop+classification 2단계는 fine-tuning 후에도 페트↔유리가 안 잡힐 때의 예비 카드로만 유지
- 학습: 전이학습(COCO pretrained) → 커스텀 데이터셋 fine-tuning
- 배포: ONNX/TensorRT 변환, 엣지에서 추론 (저가형: NCNN/ONNX Runtime CPU, 표준형: TensorRT GPU)

### 4.2 데이터셋 (v0.2 확정)
| 소스 | 내용 | 용도 |
|---|---|---|
| **AI Hub 생활폐기물(71385) 실내형분류기** | Training 102,271장 + 공식 Validation 12,784장. 밀폐 박스·상부 카메라 — 우리 스테이지와 동일 구도. 29종 코드→17클래스 매핑 | **주력 학습 (진행 중)** |
| **자체 촬영 (핵심)** | 실제 촬영 스테이지·조명 환경에서 품목별 300~500장 (dirty·other 포함) | fine-tuning 주력. 도메인 갭 제거 |
| (기각) TACO / TrashNet 등 해외 데이터 | 길거리·일상 사진 — 도메인 불일치, 투명페트 구분 없음 | 사용 안 함 |

주: AI Hub는 해외 IP 다운로드 차단 → 국내 회선으로 받아 GPU 서버에 업로드하는 파이프라인 확립 (상세: 02 문서 8장 운영 노트)

- 자체 촬영은 **실기기 조명 박스 안에서** 찍는 것이 정확도에 결정적 (배경·조명 고정 → 문제 난이도 급감)
- 증강: 회전, 밝기, 블러, 배경 노이즈. 클래스당 실효 2,000장 목표
- 학습 인프라: RunPod GPU (기존 ABC 프로젝트 파이프라인 재사용 가능)

### 4.3 난이도 대응 (v0.2 갱신)
- **비닐·종이**: 분배 대상에서 제외(기구 걸림·규격 문제). 인식은 17클래스 학습으로 수행하고 "판별불가함 + 품목 안내"로 처리 — 난이도 문제를 UX로 우회
- **투명 페트 vs 유리**: 시각적 유사 → 로드셀 무게를 보조 특징으로 (유리 평균 무게 ≫ 페트). 규칙 기반 후처리: `투명용기 && 무게 > 150g → 유리 가중`. Run A 실측에서는 혼동 미미 (both mAP50 0.99+)
- **캔**: 유도형 근접센서(금속 감지)로 교차검증 → 캔 오분류 사실상 제거
- **오염 판별(신규)**: 품목별 오염 8종을 별도 클래스로 학습 → "세척 후 배출" 안내. dirty 판정은 정밀도 우선(임계값 상향)으로 클린을 오염으로 보내는 오류 최소화

---

## 5. 하드웨어 설계 — 예산 티어별

### 5.1 저가형 (목표 ~35만원, 4–6주)

**컨셉:** 라즈베리파이 단일 보드로 추론+제어 통합. 프레임은 MDF/3D프린팅.

| 부품 | 사양 | 예상가 |
|---|---|---|
| 라즈베리파이 5 (8GB) | 추론+제어+서버 통합 | 110,000 |
| 카메라 | Pi Camera Module 3 or USB 웹캠(오토포커스) | 35,000 |
| 스텝모터+드라이버 | NEMA17 + A4988/TMC2208 | 20,000 |
| 서보 ×2 | MG996R (트랩도어) | 12,000 |
| 센서류 | IR 투입감지, 홀센서(원점), 유도형 금속센서 | 20,000 |
| 로드셀+HX711 | 5kg | 8,000 |
| 조명 | LED 바 + 디퓨저 (유백 아크릴) | 15,000 |
| 전원 | 12V 5A SMPS + 5V 변환(강압) | 20,000 |
| 프레임·외장 | MDF 레이저컷 or 3D프린팅 + 아크릴 | 60,000 |
| 수거함 7개 | 시판 소형 수납함 | 20,000 |
| 기타 (배선, 베어링, 볼트, GT2벨트) | | 30,000 |
| **합계** | | **약 350,000** |

- 추론 속도: YOLOv8n 640px, Pi 5 CPU(NCNN) 기준 약 3~5 FPS → 정지 촬영 1장 추론에 충분
- 제어: 파이 GPIO 직결 (스텝 드라이버·서보·센서). 별도 MCU 불필요 → 배선·개발 단순
- 리스크: GPIO 실시간성 한계로 스텝모터 가감속이 거칠 수 있음 → 회전 속도를 보수적으로

### 5.2 표준형 (목표 ~100만원, 2–3개월)

**컨셉:** Jetson으로 추론 고속화 + 전용 MCU로 제어 분리. 알루미늄 프로파일 프레임.

| 부품 | 사양 | 예상가 |
|---|---|---|
| Jetson Orin Nano Super (8GB) | TensorRT 추론, 수십 FPS | 380,000 |
| 카메라 | 글로벌 셔터 USB 카메라 (OV9281급) or 고품질 오토포커스 | 80,000 |
| 제어 MCU | ESP32 or 아두이노 Mega — 모터·센서 전담, Jetson과 UART/USB 시리얼 | 15,000 |
| 스텝모터+드라이버 | NEMA17 ×1~2 + TMC2209 (정숙) | 35,000 |
| 서보 ×2~4 | 메탈기어 디지털 서보 | 30,000 |
| 센서류 | IR, 홀센서, 유도형 금속센서, 도어 리미트 | 35,000 |
| 로드셀+HX711 | | 8,000 |
| 조명 | 링라이트 + 디퓨저 박스 (촬영 품질 ↑) | 40,000 |
| 전원 | 12V 10A SMPS + DC-DC 분배 | 35,000 |
| 프레임 | 2020 알루미늄 프로파일 + 아크릴 패널 | 150,000 |
| 수거함 + 턴테이블 기구 | 베어링(회전판용 터닝테이블 베어링), 제작비 | 80,000 |
| 터치 디스플레이 (선택) | 7" — 기기 전면 UI | 60,000 |
| 기타·예비 | | 50,000 |
| **합계** | | **약 1,000,000** |

- 역할 분리: **Jetson = 추론+서버+대시보드 백엔드**, **ESP32 = 상태머신 실시간 제어**. 시리얼 프로토콜(JSON 라인)로 통신 → 한쪽 재시작해도 안전
- 추론: TensorRT FP16으로 YOLO11n 30+ FPS → 실시간 프리뷰·복수 투입 감지 가능
- 확장: 터치 UI로 "이거 맞아요?" 사용자 피드백 → 재라벨링 데이터 수집 루프 (액티브 러닝 스토리)

### 5.3 공통 기구 치수 (초안)
- 전체: 약 W450 × D450 × H900 mm (스탠드형)
- 상단 1/3: 투입구+촬영 스테이지 (내부 300×300×250, 무광 백색 배경)
- 하단 2/3: 캐러셀 + 수거함 7개 (각 약 φ120×H350 원형 배치, 턴테이블 φ400)

---

## 6. 소프트웨어 설계

### 6.1 스택
| 계층 | 기술 | 비고 |
|---|---|---|
| AI 학습 | Python, PyTorch, Ultralytics, RunPod GPU | 기존 파이프라인 재사용 |
| 엣지 추론 | ONNX Runtime(저가형) / TensorRT(표준형) | |
| 기기 서비스 | Python (FastAPI + asyncio 상태머신) | 카메라·추론·제어 오케스트레이션 |
| MCU 펌웨어 (표준형) | Arduino C++ (ESP32) — 시리얼 JSON 프로토콜 | |
| DB / 실시간 | SQLite(로컬 큐) → Supabase 동기화 | 오프라인 내성: 로컬 선기록 후 업로드 |
| 대시보드 | Next.js or Streamlit + Supabase Realtime | 분류 이력, 품목별 통계, 오분류 신고 |

### 6.2 시리얼 프로토콜 (표준형, Jetson↔ESP32)
```
Jetson → ESP32 : {"cmd":"sort","slot":3}        // 3번 수거함으로
ESP32 → Jetson : {"evt":"inserted"}             // 투입 감지
ESP32 → Jetson : {"evt":"done","slot":3,"ms":4200}
ESP32 → Jetson : {"evt":"error","code":"HOMING_FAIL"}
```

### 6.3 대시보드 핵심 화면
1. 실시간 피드: 방금 분류된 품목 사진 + 클래스 + 신뢰도
2. 통계: 일/주별 품목 배출량, 재활용률, 판별불가 비율
3. 오분류 신고: 사용자가 정정 → 재학습 데이터로 축적

---

## 7. 개발 일정 (표준형 12주 기준 / 저가형은 1–5주차 압축)

| 주차 | 마일스톤 |
|---|---|
| 1–2 | 상세 설계 확정, 부품 발주, 데이터셋 수집 시작 (AI Hub + 자체) |
| 3–4 | AI 1차 학습 (공개 데이터) → 베이스라인 정확도 측정. 캐러셀 기구 프로토타입 |
| 5–6 | 프레임·기구 조립, MCU 펌웨어(상태머신·호밍·트랩도어) |
| 7–8 | 실기기 촬영 데이터 수집 → fine-tuning → 엣지 배포. HW-SW 통합 |
| 9–10 | 대시보드, Supabase 연동, 오프라인 큐. 연속 처리 테스트 |
| 11 | 신뢰도 임계값·보조센서 융합 튜닝, 오류 처리(걸림·중복투입) |
| 12 | 시연 리허설, 발표자료, 문서화 |

---

## 8. 리스크와 대응

| 리스크 | 확률 | 대응 |
|---|---|---|
| 비닐·종이 인식률 저조 | 높음 | 자체 데이터 최다 확보, 조명 고정, 최악 시 시연 품목 큐레이션 + "판별불가" UX로 방어 |
| 기구 걸림 (비닐이 트랩도어에 붙음) | 중간 | 도어 개방각 크게, 스테이지 바닥 경사, 정전기 방지 처리 |
| 부품 배송 지연 | 중간 | 1–2주차 조기 발주, 핵심 부품(보드·모터)은 국내 재고 우선 |
| 저가형 추론 속도 부족 | 낮음 | 정지 촬영 1장 방식이라 3초 이내면 충분. 입력 해상도 480px로 축소 가능 |
| 유리 파손 | 낮음 | 낙하고 15cm 제한 + 완충재. 시연은 플라스틱 재질 유리모형도 예비 |

---

## 9. 확장 아이디어 (발표 차별화 포인트)
- **액티브 러닝 루프**: 판별불가·오분류 신고 이미지를 자동 수집 → 주기적 재학습 → "쓸수록 똑똑해지는 기기"
- **투명 페트 라벨 감지**: 라벨 미제거 페트 감지 → "라벨을 제거해 주세요" 안내 (규정 준수 코칭)
- 아파트 단지 공용 설치 시나리오: 세대별 QR 태깅 → 재활용 포인트 적립 (비즈니스 모델 슬라이드)

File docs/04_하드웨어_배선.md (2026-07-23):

# 하드웨어 배선 가이드 — Pico 2 W 프로토타입

> 작성 2026-07-20. 대상: 서보 SG90 ×2, 초음파 HC-SR04, LCD1602(I2C 백팩), Pico 2 W.
> 테스트 펌웨어: `pico_hw_test/build/pico_hw_test.uf2` (시리얼 명령으로 전 장치 조작)
> Wokwi 시뮬레이션: `pico_hw_test/wokwi/` (diagram.json + main.py)

## 1. 전체 그림

```
                    ┌─ USB ─── 노트북 (시리얼 115200, PuTTY 또는 AI 원격)
              ┌─────┴─────┐
   서보1 ──── │ GP0       │
   서보2 ──── │ GP1       │        LCD1602(I2C 백팩)
              │ GP4  SDA ─│─────── SDA
              │ GP5  SCL ─│─────── SCL
   HC-SR04    │           │
    TRIG ──── │ GP16      │
    ECHO ─1k─►│ GP17      │   (1k/2k 분압: 5V→3.3V)
        └2k─GND           │
              └───────────┘
   전원: Pico·센서·LCD = USB 5V / 서보 = 별도 5V (GND만 공통)
```

## 2. 핀 연결표 (Pico 2 W, USB가 1번 줄 방향)

| 장치 | 장치 핀 | Pico 핀 | 물리핀 | 브레드보드(참고) |
|---|---|---|---|---|
| 서보1 | 신호(주황) | GP0 | 1 | C1 옆 A1/B1 |
| 서보2 | 신호(주황) | GP1 | 2 | C2 옆 A2/B2 |
| 서보 1·2 | 전원(빨강) | — | — | **별도 5V** (AA×4 홀더 +) |
| 서보 1·2 | GND(갈색) | GND | — | 파란 레일 |
| HC-SR04 | VCC | VBUS(5V) | 40 | H1 → 빨간 레일 |
| HC-SR04 | TRIG | GP16 | 21 | H20 (I20에 점퍼) |
| HC-SR04 | ECHO | → 1kΩ → GP17 | 22 | 분압 중간점 → H19(I19) |
| (분압) | 중간점 | → 2kΩ → GND | — | 파란 레일 |
| LCD | VCC | **3V3 먼저** (흐리면 VBUS) | 36 | |
| LCD | GND | GND | — | 파란 레일 |
| LCD | SDA | GP4 | 6 | |
| LCD | SCL | GP5 | 7 | |

## 3. 전원 규칙 (사고 방지 2줄 요약)

1. **서보 빨간선은 절대 Pico 핀에서 따오지 않는다** — 별도 5V(AA×4 = 6V 허용, 또는 5V 2A 어댑터). 어기면 서보 움직일 때 보드 리셋.
2. **모든 GND는 파란 레일 하나로 모은다** — Pico GND + 서보 갈색 + 센서 GND + 2k저항 + 배터리(−). GND가 안 만나면 아무것도 동작 안 함.

## 4. 테스트 방법

1. `pico_hw_test.uf2` 굽기 (BOOTSEL 누른 채 USB → 드라이브에 드래그)
2. PuTTY: COM 번호(장치관리자 확인) / 115200 → `>` 프롬프트
3. 명령:

| 명령 | 확인 내용 |
|---|---|
| `all` | 전 장치 자동 점검 (최초 1회 필수) |
| `scan` | LCD I2C 주소 탐지 (0x27/0x3F 정상) |
| `dist` / `watch` | 초음파 1회/연속 — 실패 원인 구분 출력 |
| `s1 90` `s2 45` | 서보 각도 지정 (0~180) |
| `sweep` | 서보 왕복 — 도중 리셋되면 서보 전원 미분리 |
| `lcd HELLO` `lcd2 WORLD` | LCD 1/2줄 표시 (영문·숫자만) |

## 4-1. 검증 완료 사항 (2026-07-20)

- **HC-SR04**: 정상 동작 확인 (3~4cm 근접, 259cm 원거리 모두 안정 측정)
- **LCD1602 I2C**: 백팩 매핑 **MAP A**(P0=RS, P2=EN) 확정.
  글자 깨짐의 원인은 매핑이 아니라 **초기화 타이밍 부족**이었음 →
  나이블당 150us, 초기화 6ms로 여유 확보 후 정상 표시.
  (진단 펌웨어 `lcd_test.uf2`가 MAP A/B를 6초씩 번갈아 표시하여 판별)
- **데모 펌웨어**: `sonar_lcd.uf2` — 초음파 거리를 LCD에 실시간 표시 + 10cm 진입 시 DETECTED

## 5. 문제 해결표

| 증상 | 원인 → 조치 |
|---|---|
| `에코 시작 없음` | 센서 VCC가 3V3에 꽂힘 → VBUS(5V)로 / TRIG 점퍼 확인 |
| `에코 안 끝남(반사 없음)` | 센서가 허공·천장 봄 → 정면 10~20cm에 평평한 물체 |
| `scan`에 아무것도 없음 | LCD SDA/SCL 뒤바뀜 또는 전원 미연결 |
| LCD 켜지는데 글자 안 보임 | 백팩 뒷면 파란 가변저항(콘트라스트) 돌리기 / 3V3→VBUS 승격 |
| `sweep` 중 재부팅 | 서보 전원 분리 안 됨 → 별도 5V + GND 공통 |
| 시리얼에 아무 출력 없음 | 케이블이 충전 전용 → 데이터 케이블로 교체 |

## 6. 다음 단계 (최종 기계 구조)

이 배선·펌웨어가 그대로 최종 기계의 구동부가 된다:
`Jetson Nano(카메라 C920 + 추론) ──USB시리얼── Pico(본 배선)` —
Jetson이 `s1 90` 같은 명령을 시리얼로 보내는 구조. 상세는 01_설계서 참조.

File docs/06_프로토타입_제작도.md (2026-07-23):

# 골판지 프로토타입 제작도 — 4분류기

> 작성 2026-07-21. 범위 축소안(싱귤레이터 제외 / 4칸 / 오염 무시) 기준.
> 펌웨어: `pico_sorter/build/pico_sorter.uf2` · 도면 이미지: `img/proto_cardboard_cutplan.png`

## ⚠️ v2 구조 변경 (2026-07-21 오후)

참고 제품 사진 기반으로 **회전 슈트 → 수거함 회전판(캐러셀) 방식**으로 변경. CAD 설계와 동일 철학.

| 서보 | v1 (폐기) | **v2 (현재)** |
|---|---|---|
| 서보1 (GP0) | 슈트 회전 | **투입구 왼문** |
| 서보2 (GP1) | 셔터 | **수거함 회전판** (0/60/120/180° = 4칸) |
| 서보3 (GP2) | — | **투입구 오른문** (왼문과 반대방향 동기) |

동작: 양문에 물체 → 판정 → **회전판이 칸 정렬 → 양문 개방 → 낙하 → 닫힘**.

### ⚠️ v3 실기 확정 (2026-07-22) — 실측 캘리브레이션
실물 조립 결과 **투입구는 서보 1개(단문)**로 확정. 배선·각도 실측값 (실제 작동 코드의 기준):

| 항목 | 값 |
|---|---|
| 투입구 서보 | **물리핀 1 (GP0)** — 닫힘 **90°**, 완전 열림 **180°** (증가 방향, 열림양 90) |
| 회전판 서보 | **물리핀 2 (GP1)** — 칸 각도 0/60/120/180° (실측 보정 예정) |
| 감지 | HC-SR04 (FSR 검토 후 초음파로 회귀), TRIG=GP16/ECHO=GP17 분압 |
| 테스트 펌웨어 | `pico_sonar_test.uf2` (기본값에 캘리브레이션 반영됨) |

### 분배 체계 확정 v2 — 3칸 (2026-07-23 오전 확정)

십자 프레임(팔 90° 간격)과 SG90 180° 한계에 맞춰 **3칸으로 확정** — 프레임 개조 불필요.

| 회전판 각도 | 칸 | 들어가는 것 |
|---|---|---|
| **0°** | 종이 (PAPER) | paper |
| **90°** | 플라스틱 (PLASTIC) | plastic + **투명페트**(재질 병합) |
| **180°** | 비닐 (VINYL) | vinyl (물티슈류는 fine-tuning 후) |
| 수거함 없음 | **리턴** | 캔·유리·종이팩 등 그 외 전부 + 판별불가 → `REJECT` (문 안 열림, 회수) |

- 오염 여부 감지 안 함 (`IGNORE_DIRTY=True`)
- 판정(`jetson_infer.py`·`laptop_stream.py`)·펌웨어(`pico_sonar_test`) 반영 완료

### 자동 사이클 상태머신 (펌웨어 내장)

```
[대기] --물체 감지(15cm)--> [안정화 3초] --경과--> "DETECT" 송신 → [분석대기]
                              └-치우면 취소            (초음파 무시)
[분석대기] --SORT 수신--> 회전판 정렬 → 문 열기 → 닫기 → "DONE" → [정착 2초] → [대기]
           --REJECT 수신--> 안내 표시 → 물체 회수될 때까지 대기 → [대기]
           --30초 무응답--> 안전 복귀 → [대기]
```

- 사이클 진행 중에는 초음파를 인지하지 않음 (문 개폐·회전 중 오감지 방지)
- 안정화 3초 = 사용자가 손을 빼는 시간 (LCD "WAIT 3 SEC" 안내)
아래 본문의 "회전 슈트" 관련 재단(④⑤)은 **회전판(원판 ø400 안팎) + 수거함 4개 배치**로 대체.
양문 재단: 스테이지 바닥판을 반으로 나눠 각 문 150×150, 경첩 대신 서보 축 직결.
캘리브레이션: `d1`/`d2`/`d3` 개별 각도 → `cfg c1/c3/amt/b0~b3`로 저장 (재부팅 시 초기화되므로 확정 후 코드 반영).

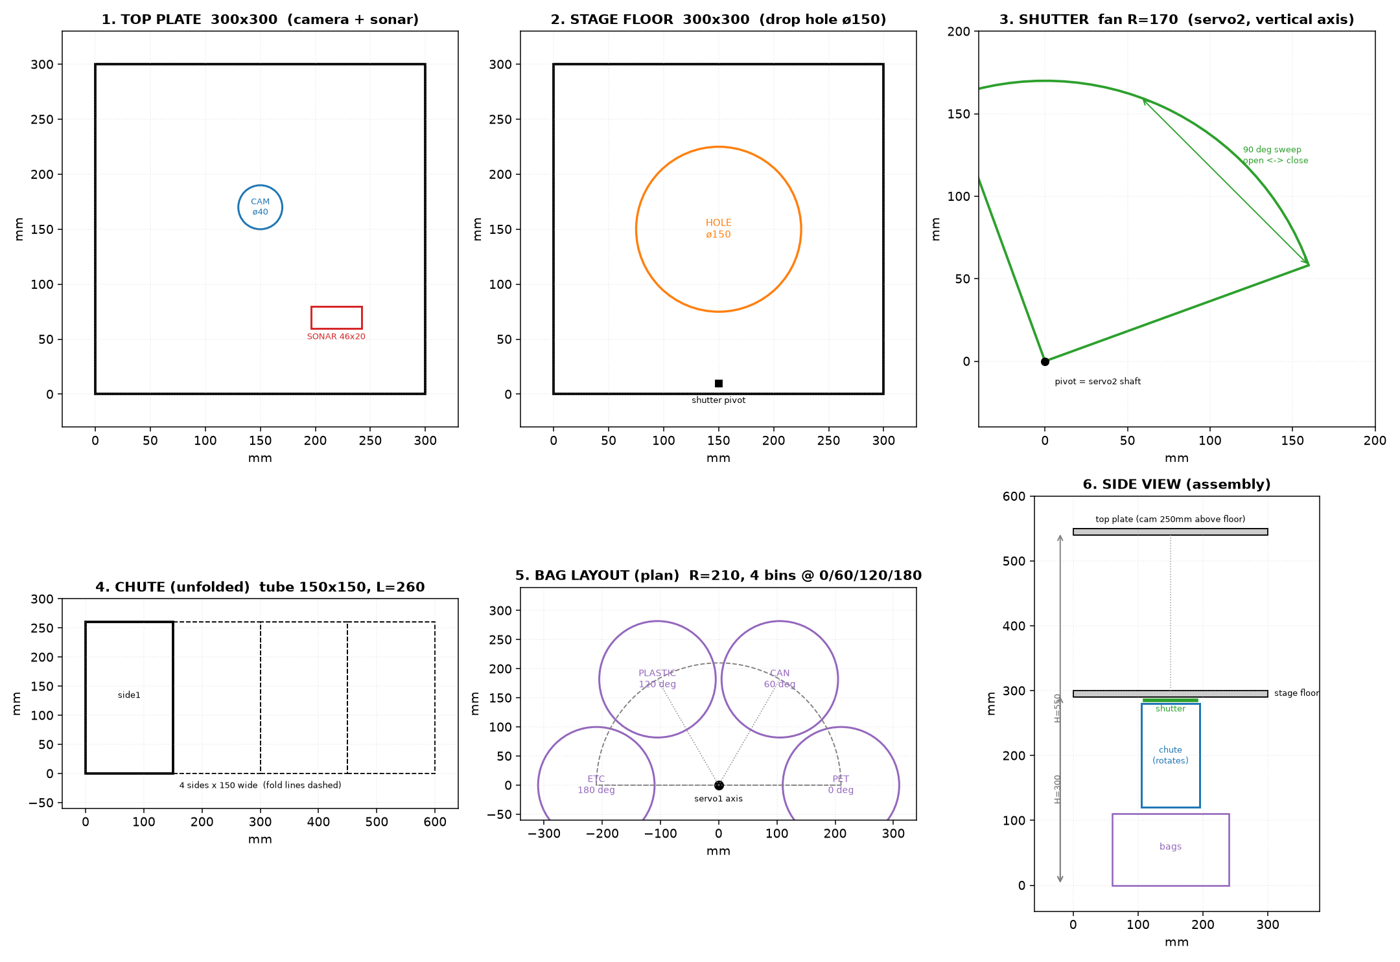
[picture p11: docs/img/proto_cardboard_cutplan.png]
재단 도면


## 1. 설계 원칙 — 왜 이 구조인가

**두 서보 모두 회전축을 수직으로 둔다.** 중력이 회전을 방해하지 않으므로,
SG90의 약한 토크(1.8kg·cm)로도 여유롭게 동작한다.
(문짝을 들어 올리는 방식이면 MDF·물체 무게에서 4kg·cm가 필요해 SG90으로는 불가)

| 서보 | 역할 | 축 | 동작 |
|---|---|---|---|
| 서보1 (GP0) | 슈트 회전 | 수직 | 0° / 60° / 120° / 180° = 4칸 |
| 서보2 (GP1) | 셔터 개폐 | 수직 | 10°(닫힘) ↔ 100°(열림) |

## 2. 재단 목록 (골판지 5T 기준)

| # | 부품 | 치수 | 수량 | 가공 |
|---|---|---|---|---|
| 1 | 상판 | 300 × 300 | 1 | 카메라 ø40 구멍(중앙에서 뒤로 20), 초음파 46×20 사각 구멍 |
| 2 | 스테이지 바닥판 | 300 × 300 | 1 | 중앙 **ø150 낙하 구멍**, 앞쪽 가장자리에 셔터축 구멍 ø4 |
| 3 | 셔터판 | 부채꼴 R170, 각도 100° | 1 | 축 구멍 ø4 (꼭짓점) |
| 4 | 슈트 | 150 × 260 × 4장 (전개 600 × 260) | 1 | 접어서 사각통, 하단을 45° 사선 컷 |
| 5 | 슈트 회전판 | ø200 원판 | 1 | 중앙 축 구멍, 슈트를 이 판에 고정 |
| 6 | 측벽 | 300 × 550 | 2 | — |
| 7 | 뒷벽 | 300 × 550 | 1 | — |
| 8 | 앞벽 | 300 × 250 (윗부분만) | 1 | 투입구 130 × 140 |

**골판지 대신 택배 상자를 재활용**해도 무방하다. 정확도가 필요한 것은 ②의 ø150 구멍과 ③ 셔터의 축 위치뿐이다.

## 3. 봉투 배치 (⚠️ 도면에서 수정된 치수)

도면 이미지는 R=210으로 그려져 있으나, **봉투 지름 200mm 기준으로는 간격이 10mm뿐이라 너무 빠듯하다.**
아래 중 하나를 택할 것:

| 안 | 회전 반경 R | 인접 봉투 중심거리 | 여유 | 전체 폭 |
|---|---|---|---|---|
| A (권장) | **240mm** | 240mm | 40mm | 약 680mm |
| B | 210mm | 210mm | 10mm | 620mm | 
| C | 210mm + 봉투 ø160 | 210mm | 50mm | 580mm |

- 중심거리 = 2 × R × sin(30°) = R (60° 간격일 때)
- 폭이 부담되면 **C안**(작은 봉투)이 현실적이다.

배치 각도: **0° = PET / 60° = CAN / 120° = PLASTIC / 180° = ETC** (펌웨어 `BIN_ANGLE`과 일치)

## 4. 조립 순서

1. **스테이지 바닥판**(②)에 ø150 구멍을 뚫고, 앞 가장자리에 서보2를 고정 (축이 위를 향하게)
2. **셔터판**(③)을 서보 혼에 결합 → 10°에서 구멍을 완전히 덮고, 100°에서 완전히 비켜나는지 손으로 확인
3. **상판**(①)을 550mm 높이에 설치, 카메라를 구멍에 끼워 아래를 보게 (스테이지 바닥까지 약 250mm)
4. 초음파 센서를 상판에 고정, **정면이 스테이지 바닥 중앙**을 향하게
5. **슈트 회전판**(⑤) 중앙을 서보1에 결합, 그 위에 접은 슈트(④)를 세워 고정
   - ⚠️ **회전판 무게를 서보축에 직접 싣지 말 것.** 볼트+와셔 또는 폐 CD 스핀들로 별도 지지하고,
     서보는 회전만 담당하게 한다 (기어 파손 방지)
6. 봉투 4개를 3항의 각도·반경에 맞춰 걸이(옷걸이·철사)로 매단다
7. 슈트 출구가 각 봉투 입구 중앙에 오는지 **손으로 4칸 전부 돌려 확인** 후 서보 결선

## 5. 배선 (기존 브레드보드 그대로)

| 장치 | 핀 |
|---|---|
| 슈트 서보 신호 | GP0 (물리핀 1) |
| 셔터 서보 신호 | GP1 (물리핀 2) |
| HC-SR04 | TRIG=GP16, ECHO=GP17 (1k/2k 분압) |
| LCD1602 I2C | SDA=GP4, SCL=GP5 |
| 서보 전원 | **건전지 AA×4 별도 레일**, GND는 전부 공통 |

상세는 [04_하드웨어_배선.md](04_하드웨어_배선.md) 참조.

## 6. 펌웨어 — `pico_sorter.uf2`

### 시리얼 프로토콜

| 방향 | 메시지 | 의미 |
|---|---|---|
| Pico → 상위 | `DETECT <cm>` | 물체 투입 감지 → 상위가 촬영·판정 시작 |
| Pico → 상위 | `CLEAR <cm>` | 물체 빠짐 |
| Pico → 상위 | `DONE <칸>` | 분배 완료 |
| 상위 → Pico | `SORT PET\|CAN\|PLASTIC\|ETC` | 해당 칸으로 분배 실행 |
| 상위 → Pico | `REJECT <사유>` | 셔터 열지 않고 리턴 안내 표시 |
| 상위 → Pico | `READY` / `BUSY` | LCD 상태 표시 |
| 상위 → Pico | `TEST` | 4칸 순회 + 셔터 자가 점검 |
| 상위 → Pico | `PING` | `PONG` 응답 (연결 확인) |

### 분배 동작 시퀀스
```
SORT CAN 수신
  → LCD "SORTING / -> CAN"
  → 슈트를 60°로 천천히 회전 (3°씩, 급가속 전류 스파이크 방지)
  → 0.25초 정착 대기
  → 셔터 열기 (100°) → 0.9초 낙하 → 셔터 닫기 (10°)
  → "DONE CAN" 송신
```

### 안전 설계
- 회전은 **3°씩 20ms 간격**으로 이동 — SG90 2개가 동시에 급가속하면 전압 강하로 보드가 리셋되는 문제를 방지
- `REJECT`는 **셔터를 열지 않는다** — 물체가 스테이지에 남아 사용자가 회수
- 초음파는 0.2초 주기, 히스테리시스 15cm/18cm (경계 떨림 방지)

## 7. 제작 후 점검 순서

1. `pico_sorter.uf2` 굽기 → 시리얼 모니터(115200) 연결
2. `PING` → `PONG` 확인
3. `TEST` → 4칸 순회 + 셔터 개폐 육안 확인 (**물체 없이 먼저**)
4. `SORT CAN` → 슈트가 60°로 가고 셔터가 열리는지
5. 페트병을 스테이지에 올려 `DETECT` 메시지가 뜨는지
6. 전체 사이클: 물체 투입 → DETECT → (상위가 판정) → SORT → 봉투에 들어가는지

## 8. 알려진 한계 (발표 시 언급할 것)

- **골판지 강성 부족**: 슈트가 흔들려 낙하 지점이 어긋날 수 있음 → 실기기는 MDF 5~12T
- **SG90 정밀도**: ±2~3° 오차 → 봉투 입구를 크게 잡아 흡수 (여유 40mm 권장 근거)
- **초음파와 연질 재료**: 비닐·천은 반사가 약해 감지를 놓칠 수 있음 → 카메라 미검출 판정이 2차 방어
- **싱귤레이터 없음**: 한 번에 하나씩 투입을 사용자가 지켜야 함. 복수 투입 시 모델이 감지해 리턴

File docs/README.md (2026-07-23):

# 문서 인덱스 — 가정용 분리수거 자동분류기

| 문서 | 내용 | 상태 |
|---|---|---|
| [00_진행일지.md](00_진행일지.md) | 일자별 작업·결정 기록 (계속 갱신) | 상시 |
| [01_설계서.md](01_설계서.md) | 시스템 전체 설계 (기구·HW·SW·일정·리스크). v0.2 | 확정 (클래스·AI 부분 갱신 완료) |
| [02_클래스_설계.md](02_클래스_설계.md) | 학습 클래스 체계 탐구·확정 (17종), 매핑·평가 방법·운영 노트 | 확정 |
| [03_학습_보고서.md](03_학습_보고서.md) | 학습 과정·결과·그래프·비용 + 실물 테스트 | Run A·B-17 완료 |
| [04_하드웨어_배선.md](04_하드웨어_배선.md) | Pico 프로토타입 배선(서보·초음파·LCD)·테스트 명령·문제해결 | 확정 |
| [05_포트폴리오_기록.md](05_포트폴리오_기록.md) | **발표·포트폴리오용 상세 서술** (의사결정 근거·시행착오·수치) | 상시 |
| [06_프로토타입_제작도.md](06_프로토타입_제작도.md) | 골판지 4분류기 재단·조립·시리얼 프로토콜 | 확정 |
| img/ | 학습 곡선·confusion matrix 등 그래프 | |

## 문서 규칙
- 프로젝트 문서는 이 폴더(docs/)에만 작성·보관한다.
- 결정이 바뀌면 과거 문서를 수정하고 버전 주석을 남긴다 (중복 문서 생성 금지).
- **작업 종료 시 3종을 함께 갱신**: 진행일지(요약) + 포트폴리오 기록(상세) + `img/` 이미지 축적.
  이미지 파일명 규칙: `hw_*`(하드웨어) `test_*`(실물 테스트) `perf_*`(성능) `cad_*`(3D) `runA/B*`(학습).
- 데이터·모델·코드 산출물은 문서가 아니므로 각각 `training/`, `models/`, 프로젝트 루트에 둔다.

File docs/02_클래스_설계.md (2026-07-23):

# 모델 학습 클래스 설계 탐구

> 2026-07-17. AI Hub 생활폐기물(71385) 공식 매핑표 + B2 실데이터(317장) + 공식 Validation(12,784장) 실측 기반.
> **진행 상태(2026-07-18 갱신): 최종 목표를 E안(17클래스, 아파트 규정 풀스펙)으로 상향 확정.**
> **Run A(4클래스 기준선) 학습 진행 중 → Run B는 9클래스 대신 17클래스로 진행 (9클래스는 17에서 추론 병합으로 재현 가능하므로 별도 학습 생략).**

## 1. 설계 목표

- 기기 동작: 4개 품목함(투명페트/플라스틱/캔/유리) + 판별불가함(오염·비대상·저신뢰)
- 학습 클래스는 기기 동작과 별개로, **데이터가 가장 잘 배울 수 있는 단위**로 정한다.
- 판별불가는 학습하지 않는다 — confidence 임계값 + 박스 수 + 센서 융합의 후처리 산물.

## 2. 후보 설계

| 설계 | 학습 클래스 | B2 실측 활용률 | 평가 |
|---|---|---|---|
| A. 4클래스 (클린만) | pet/plastic/can/glass | **13/317 (4%)** | 오염·비대상 데이터 폐기. 실내형분류기 데이터 대부분 버림 |
| B. 5클래스 (오염 단일) | 4 + contaminated | (미실측, ~79%) | 오염 클래스의 시각 다양성 큼 → 학습 난도 ↑ |
| C. 8클래스 (품목별 오염) | 4 + {pet,plastic,can,glass}_dirty | **250/317 (79%)** | 데이터 원형(품목×상태)과 일치. 오염 4종 추론 후 병합 |
| **D. 9클래스 (채택)** | 8 + other(비대상) | **317/317 (100%)** | 비닐→플라스틱 오분류를 other가 흡수. 데이터 전량 활용 |

공식 Validation 실내형분류기 전체(12,784장) 실측에서도 동일 경향 재확인: **모드 4 활용률 38% vs 모드 9 100%.**

### E. 17클래스 (2026-07-18 최종 채택) — 아파트 규정 풀스펙

클린 9종(4품목 + paper, paper_pack(우유팩+종이컵), vinyl, styrofoam, battery) + 품목별 오염 8종.
**other 클래스 소멸** — 아파트 분리배출 규정의 전 품목을 커버하므로 "비대상" 개념이 사라짐.

- 채택 근거: ① 9클래스의 상위집합 — 추론 병합으로 9클래스/5칸 동작 재현 가능 ② 데이터 활용 100% 유지
  ③ 기구는 5칸을 유지하더라도 신규 품목은 "안내 메시지"(배출 코칭)로 활용 ④ 아파트형(9~10칸) 확장 시 재학습 불필요
- Validation 실측(12,784장): 활용 100%, 17클래스 전부 존재. 최소 클래스 paper_dirty 202박스
  (Training 환산 ~1.6천 추정) — 학습 가능선이나 소수 클래스 가중치 필요.
- 추론 병합 계층: 17클래스 → (현 기기) 4품목함 + 판별불가함(dirty 8종+신규품목 5종, 품목명 안내 포함)
  → (아파트형) 9칸 + 판별불가함(dirty만).

### D안 채택 근거
1. **데이터 활용률**: B2 기준 4% → 100%. 실내형분류기 파트가 오염 위주 배치를 다수 포함하므로 격차가 실질적.
2. **비대상 방어**: 시연·실사용 중 비닐/종이 투입은 반드시 발생. other 클래스가 없으면
   비닐봉지가 plastic으로, 종이컵이 pet으로 오분류될 위험. other가 있으면 "비대상 → 판별불가함 + 안내"로 처리.
3. **오염 품목별 유지**: 오염은 품목 형태와 결합될 때 시각 일관성이 높음(단일 오염 클래스보다 학습 유리).
   대시보드에 품목별 오염 통계 부가 효과.

## 3. 최종 매핑 (convert_aihub_to_yolo.py 모드 "9")

| idx | 클래스 | AI Hub 코드 | 전체 박스 수(3환경 합) |
|---|---|---|---|
| 0 | pet_transparent | c_5_01, c_5_02 | 335,781 |
| 1 | plastic | c_6 | 291,622 |
| 2 | can | c_3 | 68,258 |
| 3 | glass | c_4_01_*, c_4_02_*, c_4_03 | 92,302 |
| 4 | pet_dirty | c_5_01_01, c_5_02_01 | 150,453 |
| 5 | plastic_dirty | c_6_01 | 305,772 |
| 6 | can_dirty | c_3_01 | 14,646 |
| 7 | glass_dirty | c_4_03_01 | 11,521 |
| 8 | other | c_1*, c_2*, c_7*, c_8*, c_9 | 297,880 |

주: 부속품(라벨·뚜껑, c_5_01/c_4_*_01)은 클린에 포함 — 분리배출 권장사항일 뿐 품목 판별에는 클린과 동일.

## 4. 추론 → 기기 동작 병합 규칙

```
결과 클래스        → 수거함
0 pet_transparent → 투명페트함
1 plastic         → 플라스틱함
2 can             → 캔함        (금속센서 불일치 시 판별불가)
3 glass           → 유리함      (로드셀 무게로 pet↔glass 교차검증)
4~7 *_dirty       → 판별불가함  + "세척 후 배출" 안내
8 other           → 판별불가함  + "이 기기는 용기류 전용" 안내
박스 0개           → 재촬영 1회 → 판별불가
박스 2개 이상      → 리턴(싱귤레이터) 또는 판별불가
max conf < 0.6    → 판별불가
```

## 5. 알려진 리스크와 대응

| 리스크 | 대응 |
|---|---|
| clean↔dirty 라벨 경계 애매(B2 실물 확인) | dirty 판정은 정밀도 우선: dirty 클래스에 한해 conf 임계값 상향(예 0.7). 애매하면 클린 품목으로 |
| can_dirty(1.4만)·glass_dirty(1.1만) 소수 | 클래스 가중치 또는 dirty 4종을 유지하되 성능 미달 시 pet/plastic_dirty만 남기고 can/glass_dirty→other로 병합하는 축소 실험 |
| other 시각 다양성 큼 | other는 "정확히 뭔지"가 아니라 "4품목이 아님"만 맞히면 됨. recall 목표를 낮게(0.8) 잡고 임계값으로 조정 |
| 클래스 불균형(plastic_dirty 30만 vs glass_dirty 1.1만) | 클래스당 상한 다운샘플링(예: 3만) 후 학습 |

## 6. 실험 계획

1. **Run A (기준선)**: 4클래스, 실내형분류기 클린 데이터만 — 클린 4종 mAP 기준값 확보 ← **현재 단계**
2. **Run B (본명)**: 9클래스, 클래스 균형 샘플링 — 판정 기준: 클린 4종 mAP가 Run A 대비 -1%p 이내면 채택
3. 채택안으로 자체 촬영 fine-tuning (실기기 조명 박스, 클래스당 300~500장 — dirty/other 포함 촬영)

평가지표: 클린 4종 mAP50 ≥ 0.95 / dirty 그룹 precision ≥ 0.9 / other recall ≥ 0.8
시스템 지표(센서 융합 후): 정분류 ≥ 95%, 오분류 ≤ 2% (나머지 판별불가 허용)

## 7. 평가 방법 (2026-07-17 갱신)

- **최종 평가는 공식 Validation 실내형분류기 세트(12,784장, 학습 미사용)로 수행** — 자체 9:1 분할 점수는 학습 중 참고용으로만.
- Validation 실측 분포(9클래스 박스): other 7,553 / glass 3,598 / can 1,167 / pet 1,043 /
  plastic 1,005 / pet_dirty 924 / plastic_dirty 874 / glass_dirty 226 / can_dirty 212.
  glass 비중이 Training 추정과 다름 → Run A/B 비교는 클래스별 지표로 판정(전체 mAP 단일 숫자 금지).
- **B폴더(조명 조건)별 분해 평가 병행** — B10 등 극단 저조도 배치가 존재. 실기기는 조명을 통제하므로
  밝은 배치(B1급) 성능이 실배포 기대치에 가깝고, 저조도 배치 점수는 조명 설계의 중요성 근거로 활용.

## 8. 운영 노트

- AI Hub는 해외 IP 다운로드를 차단 → RunPod(해외)에서 직접 다운로드 불가.
  **로컬(국내) 다운로드 → rsync 업로드** 경로 확정. RunPod 기본 이미지에 rsync 없음(apt 설치 필요).
- Training 실내형분류기 B1~B10=16GB(127,844장), Validation 동 구성=2GB(12,784장) 로컬 보관:
  `training/aihub_download/`

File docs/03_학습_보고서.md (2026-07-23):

# AI 모델 학습 보고서

> 최종 갱신 2026-07-18. Run A 완료 / Run B-17 진행 중 (완료 시 본 문서 갱신 예정).
> 클래스 정의·채택 근거는 [02_클래스_설계.md](02_클래스_설계.md) 참조.

## 1. 학습 개요

| 항목 | 내용 |
|---|---|
| 데이터 | AI Hub 생활폐기물(71385) 실내형분류기 Training B1~B10 — 102,271장 / 16GB |
| 평가 | 공식 Validation 실내형분류기 12,784장 (학습 미사용, 최종 성적표 전용) |
| 모델 | YOLO11n (2.6M 파라미터) — COCO 사전학습에서 전이학습 |
| 인프라 | RunPod A40 48GB ($0.44/hr), 국내 IP로 로컬 다운로드 후 rsync 업로드 |
| 파이프라인 | aihubshell 다운로드 → `training/convert_aihub_to_yolo.py` (모드 4/9/17) → yolo train → 공식 val 평가 |

## 2. Run A — 4클래스 기준선 (완료)

### 설정
- 클래스 4종(클린만): pet_transparent / plastic / can / glass
- 학습 39,643장 (train 35,679 / self-val 3,964) — 활용률 38% (비대상 포함 이미지 제외 정책)
- 80 epoch, 640px, batch 64, workers 8 — **5.17시간, 약 $2.3**

### 결과 — 공식 Validation 4,865장 (모델이 처음 보는 데이터)

| 클래스 | Precision | Recall | mAP50 | mAP50-95 |
|---|---|---|---|---|
| **전체** | 0.984 | 0.963 | **0.985** | 0.961 |
| 투명페트 | 0.988 | 0.971 | 0.991 | 0.968 |
| 플라스틱 | 0.972 | 0.910 | 0.962 | 0.935 |
| 캔 | 0.987 | 0.974 | 0.994 | 0.973 |
| 유리 | 0.990 | 0.998 | 0.991 | 0.967 |

- **목표(클린 mAP50 ≥ 0.95) 전 클래스 통과.** 자체 val(0.989) 대비 공식 val(0.985) 격차 0.4%p → 도메인 과적합 없음
- 약점: 플라스틱 recall 0.910 (형태 다양성) — Run B-17 개선 관찰 대상
- 추론 속도: A40 기준 0.9ms/장 (Pi 5 CPU 환산 0.3~0.5초 예상 — 8초 사이클 내 여유)

### 학습 곡선

Run A curves

- val 손실이 전 구간 하락(역전 없음) → 과적합 없음. mAP는 13에폭경 수렴 → Run B 에폭 60으로 축소 근거
- (val 손실 < train 손실은 증강이 train에만 적용되는 YOLO 정상 패턴)

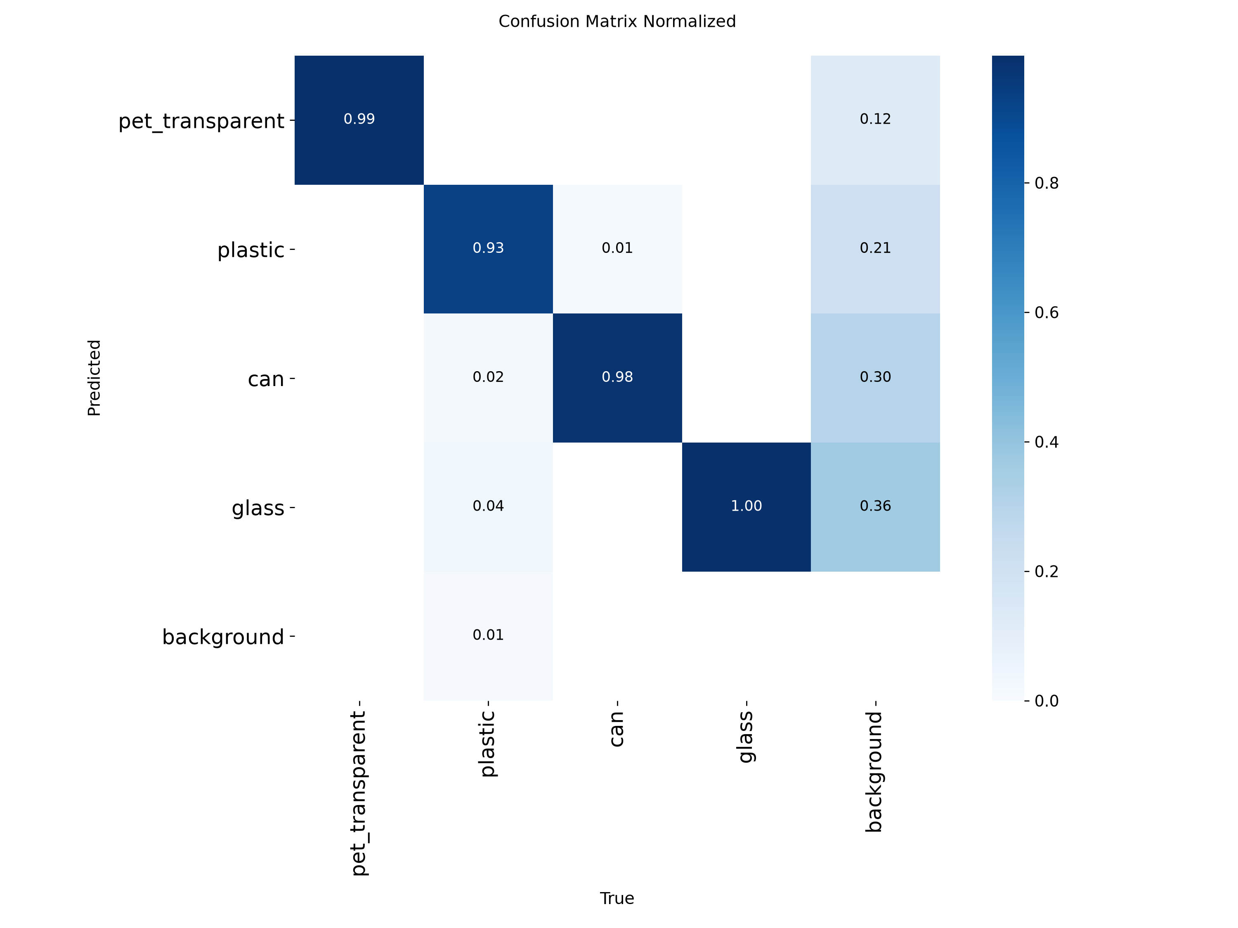
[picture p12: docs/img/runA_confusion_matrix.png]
Run A confusion matrix


### 산출물
- 모델: `models/runA_yolo11n_4cls_best.pt` (5.3MB)
- 원본 로그·곡선: `training/results_runA/`

## 3. Run B-17 — 아파트 규정 풀스펙 (진행 중)

### 설정
- 클래스 17종: 클린 9(4품목+종이/종이팩/비닐/스티로폼/건전지) + 품목별 오염 8
- 학습 102,271장 전량 (활용률 100%), 60 epoch, batch 128, workers 8
- 1차 시도 OOM 종료(컨테이너 RAM 한도 50GB, workers 24가 원인) → workers 8로 재시작

### 결과 — 공식 Validation 12,784장 (2026-07-18 완료)

전체: mAP50 **0.912** / mAP50-95 0.880. 클래스별 mAP50:

| 클린 | mAP50 | 오염 | mAP50 |
|---|---|---|---|
| glass | 0.987 | styrofoam_dirty | 0.985 |
| styrofoam | 0.987 | paper_pack_dirty | 0.972 |
| battery | 0.983 | vinyl_dirty | 0.935 |
| can | 0.977 | pet_dirty | 0.930 |
| paper | 0.973 | plastic_dirty | 0.849 |
| vinyl | 0.944 | glass_dirty | 0.838 |
| pet_transparent | 0.922 | can_dirty | 0.833 |
| paper_pack | 0.890 | paper_dirty | 0.642 |
| plastic | 0.850 | | |

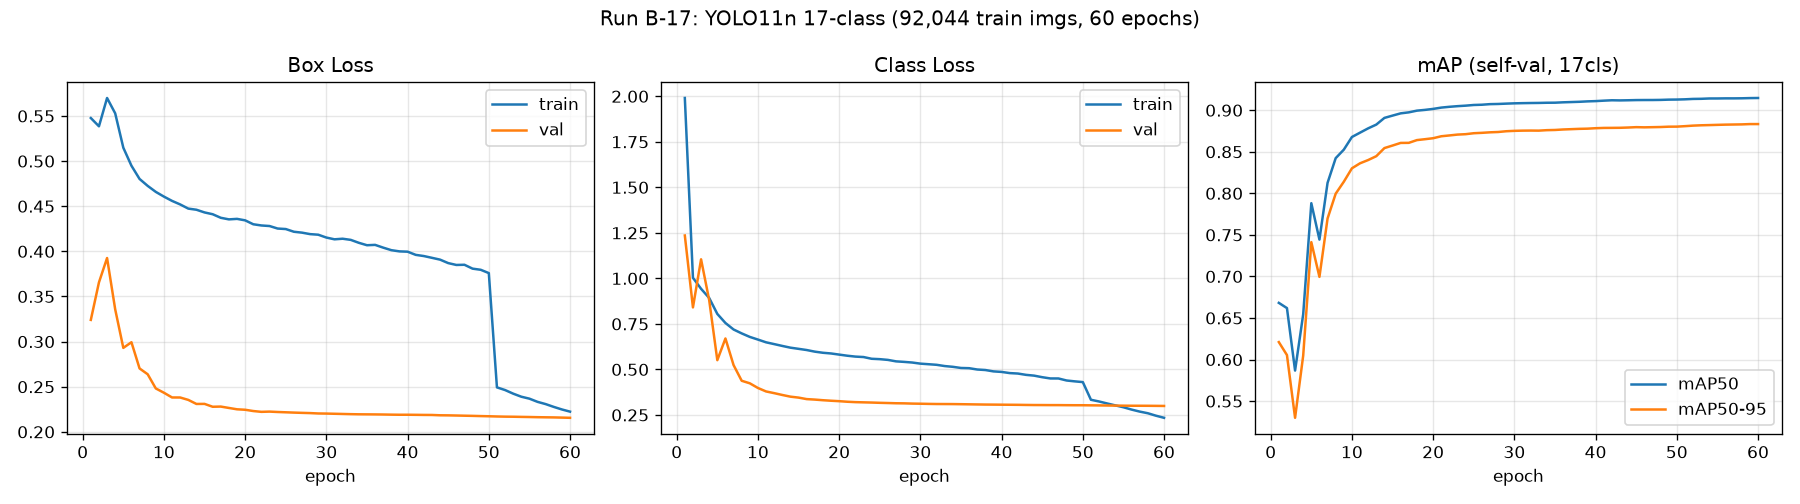
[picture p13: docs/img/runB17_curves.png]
Run B-17 curves

Run B-17 confusion matrix

### 판정 (게이트 대비)

- [x] 신규 품목 recall ≥ 0.8 → **통과** (paper 0.963, vinyl 0.919 등)
- [ ] 클린 4종 mAP50 Run A 대비 -1%p 이내 → **표면상 미달** (pet 0.991→0.922, plastic 0.962→0.850)
- **단, confusion matrix 분석 결과 하락분의 대부분은 "같은 품목의 클린↔오염 혼동"**
  (pet 오류의 13/17%p가 pet_dirty행, plastic 오류의 11/15%p가 plastic_dirty행.
   타 품목 오분류는 1~3% 수준으로 Run A와 동급)
- **품목(재질) 레벨 병합 시 정확도: 페트류 96% / 플라스틱류 91% / 캔류 97% / 유리류 98%**
  → 분배 판정을 "품목 병합"으로 하면 Run A급 유지, 오염 여부는 별도 임계값 후처리로

### 채택안 (실무 결론)

**Run B-17 단일 모델 채택 + 2단 후처리**:
1. 분배 = 품목 병합 판정 (pet+pet_dirty→페트류 …) — 정확도 Run A급
2. 오염 표시 = dirty 신뢰도가 명확할 때만 판별불가함行 (정밀도 우선 임계값)
   — 클린↔오염 라벨 경계 노이즈(구축 데이터 특성, B2 실물 확인)는 모델이 아니라 운용으로 흡수
3. paper_dirty(0.642) 등 소수 오염 클래스는 안내 기능에서 제외 가능 (분배 무관)

### 운영 사고 기록
- 1차 시도: workers=24 → 컨테이너 RAM 50GB 한도 OOM
- 2차: workers=8로 60ep 완주. 단 학습 후 자동 검증 단계에서 재차 OOM(Killed)
  → 가중치는 무사, 공식 평가는 batch=32로 별도 실행. 교훈: **학습·평가 배치를 분리 설정할 것**

## 4. 실물 웹캠 테스트 (2026-07-18~19)

노트북 웹캠 + 검은 천 배경, 일반 생활용품 12장 (`inference/watch_and_predict.py` 채택 후처리 적용).

| 결과 | 건수 | 비고 |
|---|---|---|
| 정확 판정 | 3 | 투명 트레이→플라스틱 80% 분배, 키친타올→종이 76% 배출 코칭 |
| 판별불가(저신뢰 34~45%) | 5 | 안전망 정상 작동 — 잘못된 수거함 분배 **0건** |
| 미검출 | 2 | 물체가 어두운 노출에 묻힘 |
| 오판 | 2 | 세제통(plastic_dirty 85% + 캡→battery 59%), 물티슈(paper 67% + 유령 glass 75%) → 복수 투입 오판 |

### 원인 분석 (오류 3유형 → 근본 원인 3계층)

1. **도메인 갭** — 학습 데이터(실내형분류기)는 균일 조명·선명 초점·물체가 프레임 대부분 차지.
   웹캠은 노출 부족·초점 블러·천 주름 명암. 유령 glass는 프레임 가장자리의 어두운 빈 영역에서 발생
   (학습 유리병 다수가 짙은 갈색·녹색 → 어두운 세로 명암 패턴을 병 실루엣으로 오인, 경계 잘림 박스에 모델이 관대).
2. **경량 모델의 형태·색 프라이어 의존** — 투명 펌프캡→battery(학습 내 유일한 소형 원통 클래스),
   파란 물결 그래픽 라벨→plastic_dirty(오염=표면 불규칙 유색 패턴으로 학습됨),
   물티슈 연포장→paper(학습 vinyl은 구겨진 투명 봉투 위주, 매트한 인쇄면은 종이와 유사).
3. **후처리 허점** — 복수 투입 판정에 박스 위치·크기 검증이 없어 유령 박스 1개가 곧바로 오판으로 승격.

### 대응
- (즉시) 데모 스크립트에 스테이지 ROI + 최소 박스 면적 필터 → 유령 억제
- (실기기) 균일 무광 배경 + 밝은 확산 조명 → 원인 1 구조적 해소
- (fine-tuning) 촬영 목록 확정 근거 확보: 그래픽 라벨 용기, 물티슈류 연포장, 소형 캡·뚜껑, 투명 트레이 다각도

## 5. 이후 계획

1. Run B-17 완료 → 공식 Validation 17클래스 평가 + 4클래스 병합 비교 → 본 문서 갱신
2. (조건부) 기준 미달 시: YOLO11s 승급 또는 소수 dirty 클래스 축소 실험
3. 실기기 완성 후: 조명 박스 자체 촬영 fine-tuning (클래스당 300~500장) — 최종 정확도 결정 단계
4. 배포: best.pt → NCNN/ONNX(Pi 5), 확장 시 Hailo-8L/RKNN/STM32N6 경로 (설계서 참조)

## 6. 비용 실적

| 항목 | 비용 |
|---|---|
| 파이프라인 검증 (7/16) | $0.11 |
| Run A (학습 5.2h + 대기·업로드) | 약 $4 |
| Run B-17 (진행 중, 예상) | $3~4 |
| **누적 (예상)** | **$8 안팎** — 당초 예산 $10~20 내 |

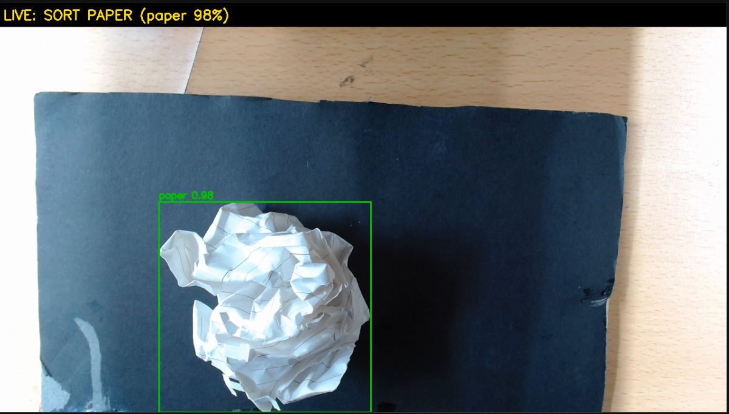
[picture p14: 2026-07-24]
docs/실제 쓰레기 테스트 오버레이/paper.png

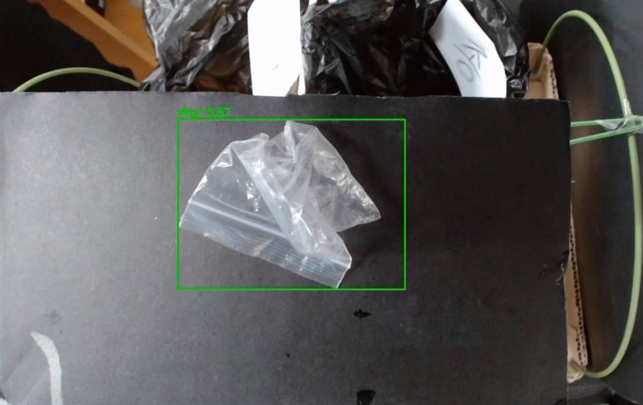
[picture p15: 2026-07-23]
docs/img/paper_detected.png

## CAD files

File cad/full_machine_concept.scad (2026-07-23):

// ============================================================
// 가정용 분리수거 자동분류기 — 실현가능성 우선 재설계 v1.0
// 단위: mm | OpenSCAD | 색상은 F5(미리보기)
//
// ★ 설계 철학: "만들 수 있는 것만 그린다"
//   - 기본 = 시연기(1개 투입). bulk_module=true 로 벌크 확장 표시
//   - MDF 12mm 판재 + 3D프린팅 소품 + 시판 원형통으로 제작 가능한 형태
//   - 과설계 제거: 외닫이 트랩도어(서보1), 게이트/리턴슈트 없음
//     (복수투입은 YOLO 박스 카운트 → 판별불가함으로 처리)
//
// ★ 코드 내장 검증 (F5 시 콘솔 echo 출력):
//   [1] 카메라 화각  [2] 유리 낙하고  [3] 2L 페트 수거함 수용
// ============================================================

bulk_module = false;   // ← true 로 바꾸면 호퍼+컨베이어 확장 표시
cutaway = false;       // ← true: 앞쪽 절반을 잘라 내부 구조 보기

$fn = 48;
t = 12;                                   // MDF 판 두께

// ---------------- 치수 (시연기 본체) ----------------
W = 580;  D = 420;  H = 880;              // 본체 외형
cx = 260; cy = D/2;                       // 캐러셀 축 (좌측 치우침)
orbit = 140;                              // 수거함 궤도 반경
drop_x = cx + orbit;                      // ★ 고정 수직 낙하선 x = 400
bin_r = 65; bin_h = 340;                  // 수거함 (2L: ⌀110×310 수용)
turn_r = orbit + bin_r + 8;               // 턴테이블 반경 = 213
turn_z = 60;                              // 턴테이블 상면 높이
stage_s = 260; stage_h = 240;             // 촬영 스테이지 내부
stage_z = turn_z + t + bin_h + 120;       // 수거함 상단 +120: 문짝 스윙(106)+낙하고(≤150) 동시 충족
cam_h  = stage_h - 20;                    // 카메라 높이(스테이지 바닥 기준)
inlet_w = 130; inlet_h = 140;             // 규격 투입구 (⌀110 페트 대응)

// ---------------- 검증 echo ----------------
fov_need = 2 * atan((stage_s/2) / cam_h);
echo(str("[검증1] 필요 화각 = ", round(fov_need), "° (PiCam3 수평 66° → ",
         fov_need < 66 ? "OK" : "부족! 스테이지 축소 필요", ")"));
echo(str("[검증2] 유리 낙하고(트랩도어→수거함 상단) = ", stage_z - (turn_z+t+bin_h),
         "mm (목표 ≤150 OK, 수거함 바닥 EVA폼 별도)"));
echo(str("[검증3] 수거함 내경 ", (bin_r-4)*2, "mm·깊이 ", bin_h,
         "mm vs 2L페트 ⌀110×310 → ", ((bin_r-4)*2>110 && bin_h>310) ? "OK" : "부족"));
door_drop = (stage_s/2) * sin(55);
clearance = stage_z - (turn_z + t + bin_h);
echo(str("[검증4] 양문 트랩도어 개방시 하강 ", round(door_drop), "mm vs 수거함까지 여유 ",
         clearance, "mm → ", door_drop < clearance ? "OK" : "충돌! 도어 축소 필요"));
echo(str("[치수] 스테이지 바닥 z=", stage_z, " / 본체 ", W, "x", D, "x", H));

// ---------------- 색상 ----------------
c_mdf   = [0.85, 0.78, 0.62];             // MDF
c_clear = [0.6, 0.75, 0.85, 0.55];                // 아크릴 창
c_mech  = [0.35, 0.45, 0.85];
c_bin   = [0.5, 0.75, 0.95];
c_rej   = [0.55, 0.55, 0.55];
c_dark  = [0.2, 0.2, 0.2];

// ============================================================
// 본체 캐비닛 (MDF 판재 구조 — 실제 재단 가능한 6면 구성)
// ============================================================
module cabinet_body() {
    color(c_mdf) {
        cube([W, t, H]);                                  // 뒷벽 (y=0)
        translate([0, D-t, 0]) difference() {             // 앞벽
            cube([W, t, H]);
            // 규격 투입구 (스테이지 정면, 낙하선 위치)
            translate([drop_x-inlet_w/2, -1, stage_z+40]) cube([inlet_w, t+2, inlet_h]);
            // 수거함 회수 도어 개구 (하부)
            translate([cx-170, -1, 40]) cube([340, t+2, bin_h+60]);
        }
        cube([t, D, H]);                                  // 좌벽
        translate([W-t, 0, 0]) cube([t, D, H]);           // 우벽
        translate([0, 0, H-t]) cube([W, D, t]);           // 천장
        cube([W, D, t]);                                  // 바닥
        difference() {                                    // 중판 (스테이지 받침)
            translate([0, 0, stage_z-t]) cube([W, D, t]);
            translate([drop_x-stage_s/2+10, cy-stage_s/2+10, stage_z-t-1])
                cube([stage_s-20, stage_s-20, t+2]);
        }
    }
    // 투입구 플랩 도어 (위 힌지, 반개방)
    color(c_mech, 0.9) translate([drop_x-inlet_w/2, D-t, stage_z+40+inlet_h])
        rotate([30, 0, 0]) translate([0, 0, -inlet_h]) cube([inlet_w, 4, inlet_h]);
    // 하부 회수 도어 (아크릴, 닫힌 상태) + 손잡이
    color(c_clear) translate([cx-170, D-2, 40]) cube([340, 4, bin_h+60]);
    color(c_dark)  translate([cx+130, D+2, 40+bin_h/2]) cube([8, 6, 60]);
    // 7" 디스플레이 (투입구 왼쪽) + 상태 LED 바
    color(c_dark)     translate([60, D-t+12.5, stage_z+30]) cube([160, 4, 110]);
    color([0.1,0.5,1]) translate([70, D-t+13, stage_z+40]) cube([140, 4.2, 90]);
    color([0.2,1,0.4]) translate([60, D-t+12.5, stage_z+150]) cube([160, 3, 6]);
    // 투입구 베젤 (3D프린팅 링, 규격 강조)
    color([0.9,0.55,0.15]) translate([drop_x-inlet_w/2-8, D-t+12, stage_z+32])
        difference() {
            cube([inlet_w+16, 5, inlet_h+16]);
            translate([8, -1, 8]) cube([inlet_w, 7, inlet_h]);
        }
    // 고무발 4개
    color(c_dark) for (p=[[30,30],[W-30,30],[30,D-30],[W-30,D-30]])
        translate([p[0], p[1], -14]) cylinder(r=18, h=14);
}

module cabinet() {
    if (cutaway) difference() {
        cabinet_body();
        translate([-50, cy+30, -30]) cube([W+700, D, H+100]);
    } else cabinet_body();
}

// ============================================================
// 캐러셀: 턴테이블(MDF 원판) + 시판 원형통 5개 + NEMA17 + 홀센서
//   i=0 칸이 낙하선(drop_x) 아래 정렬 상태
// ============================================================
module carousel() {
    color(c_mdf) translate([cx, cy, turn_z]) cylinder(r=turn_r, h=t);
    for (i = [0 : 4]) {
        ang = i * 72;
        col = (i == 4) ? c_rej : c_bin;
        color(col)
        translate([cx + orbit*cos(ang), cy + orbit*sin(ang), turn_z+t])
            difference() {
                cylinder(r=bin_r, h=bin_h);
                translate([0, 0, 4]) cylinder(r=bin_r-4, h=bin_h);
            }
    }
    // 구동: NEMA17 + GT2 벨트 감속 (토크 여유 확보)
    color(c_dark) {
        translate([cx, cy, turn_z-46]) cylinder(r=6, h=46);            // 축
        translate([cx+turn_r-60, cy+turn_r-40, t]) cube([42, 42, 40]); // NEMA17
    }
    color([0.9,0.1,0.1]) translate([cx+turn_r-12, cy-6, turn_z+t]) cube([10,10,4]);  // 마그넷
    color(c_dark) translate([cx+turn_r+4, cy-8, turn_z-10]) cube([8,16,24]);         // 홀센서
    // 턴테이블 가장자리 지지 롤러 3개 (중심축 단독 하중 방지 — 실제 필수 부품)
    color([0.4,0.4,0.45]) for (a=[30, 150, 270])
        translate([cx+(turn_r-22)*cos(a), cy+(turn_r-22)*sin(a), turn_z-16])
            cylinder(r=14, h=14);
    // GT2 감속: 센터 대풀리 + 모터 소풀리 + 벨트
    color(c_dark) translate([cx, cy, turn_z-28]) cylinder(r=34, h=10);
    color(c_dark) translate([cx+turn_r-39, cy+turn_r-19, t+40]) cylinder(r=10, h=10);
    color([0.1,0.1,0.1]) hull() {
        translate([cx, cy, turn_z-26]) cylinder(r=35, h=6);
        translate([cx+turn_r-39, cy+turn_r-19, turn_z-26]) cylinder(r=11, h=6);
    }
}

// ============================================================
// 촬영 스테이지 — 낙하선 위 오프셋. 외닫이 트랩도어(서보 1)
// ============================================================
module stage() {
    offx = drop_x - stage_s/2;
    offy = cy - stage_s/2;
    // 조명 박스 (내벽 무광백)
    color([0.97,0.97,0.95,0.75]) translate([offx, offy, stage_z])
        difference() {
            cube([stage_s, stage_s, stage_h]);
            translate([6,6,-1]) cube([stage_s-12, stage_s-12, stage_h-5]);
            translate([stage_s/2-inlet_w/2, stage_s-7, 30]) cube([inlet_w, 8, inlet_h]); // 투입 연결구
        }
    // 양문 트랩도어 (서보 2) — 외닫이는 개방시 수거함과 충돌(검증4)하여 기각
    color(c_mech) {
        translate([offx, cy, stage_z]) rotate([0, 55, 0])
            translate([0, -stage_s/2, -5]) cube([stage_s/2, stage_s, 5]);
        translate([offx+stage_s, cy, stage_z]) rotate([0, -55, 0])
            translate([-stage_s/2, -stage_s/2, -5]) cube([stage_s/2, stage_s, 5]);
    }
    color(c_dark) {   // MG996R ×2 (양측 힌지 구동)
        translate([offx-26, cy-13, stage_z-30]) cube([26, 26, 26]);
        translate([offx+stage_s, cy-13, stage_z-30]) cube([26, 26, 26]);
    }
    color([0.75,0.75,0.78]) for (xx=[offx-3, offx+stage_s-3])   // 경첩 4개
        for (yy=[cy-stage_s/2+30, cy+stage_s/2-30])
            translate([xx, yy-12, stage_z-6]) rotate([-90,0,0]) cylinder(r=6, h=24);
    // 상부: 카메라 + LED 링
    color(c_dark) translate([drop_x, cy, stage_z+stage_h]) cylinder(r=16, h=24);
    color([1,1,0.8]) translate([drop_x, cy, stage_z+stage_h-8])
        difference() { cylinder(r=55, h=5); translate([0,0,-1]) cylinder(r=44, h=7); }
    // 로드셀 (트랩도어 힌지측 하부 브래킷)
    color([0.75,0.75,0.78]) translate([offx-8, cy-40, stage_z-22]) cube([8, 80, 16]);
    // 카메라 화각 표시 (반투명 원뿔)
    color([1, 1, 0.4, 0.12]) translate([drop_x, cy, stage_z])
        cylinder(r1=stage_s/2*0.95, r2=8, h=cam_h);
}

// ============================================================
// 수직 드롭 가이드 (비산 방지 원통) + 전장부
// ============================================================
module drop_guide() {
    bin_top = turn_z + t + bin_h;
    color([0.98,0.85,0.3,0.6]) difference() {
        hull() {   // 깔때기: 입구는 열린 문짝까지 삼키는 폭, 출구는 수거함 안
            translate([drop_x, cy, stage_z-18]) cylinder(r=stage_s/2+6, h=4);
            translate([drop_x, cy, bin_top+4]) cylinder(r=bin_r+16, h=4);
        }
        hull() {
            translate([drop_x, cy, stage_z-19]) cylinder(r=stage_s/2, h=6);
            translate([drop_x, cy, bin_top+3]) cylinder(r=bin_r+10, h=6);
        }
    }
}
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

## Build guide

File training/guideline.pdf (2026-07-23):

# 인공지능 학습용 데이터 구축·활용 가이드라인

## < 생활폐기물 데이터 활용·환류 >

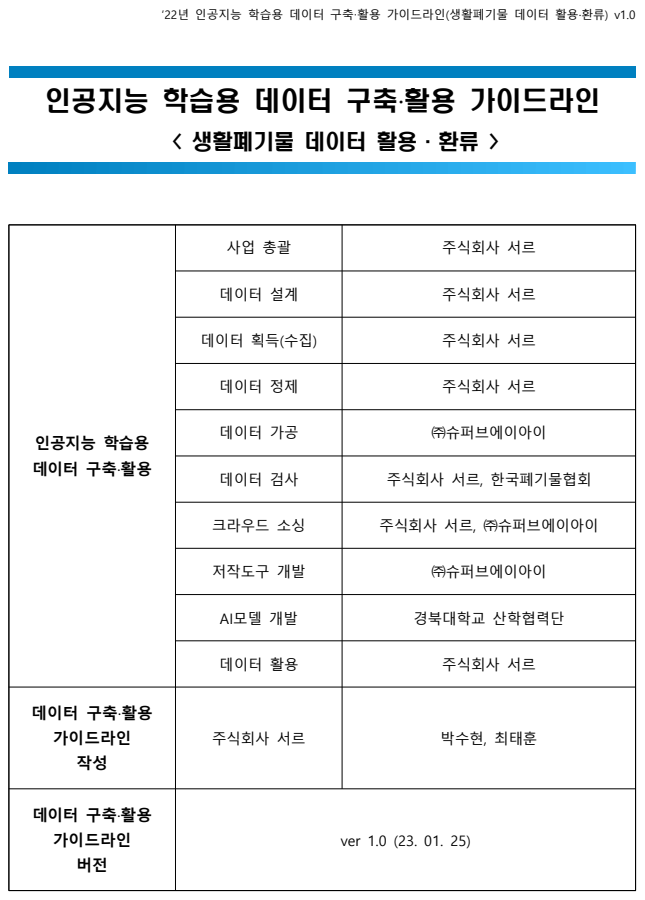
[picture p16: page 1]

‘22년 인공지능 학습용 데이터 구축·활용 가이드라인(생활폐기물 데이터 활용·환류) v1.0

사업 총괄 | 주식회사 서르

데이터 설계 | 주식회사 서르

데이터 획득(수집) | 주식회사 서르

데이터 정제 | 주식회사 서르

데이터 가공 | ㈜슈퍼브에이아이

인공지능 학습용
데이터 구축·활용

데이터 검사 | 주식회사 서르, 한국폐기물협회

크라우드 소싱 | 주식회사 서르, ㈜슈퍼브에이아이

저작도구 개발 | ㈜슈퍼브에이아이

AI모델 개발 | 경북대학교 산학협력단

데이터 활용 | 주식회사 서르

데이터 구축·활용 가이드라인 작성 | 주식회사 서르 | 박수현, 최태훈

데이터 구축·활용 가이드라인 버전 | ver 1.0 (23. 01. 25)

## 제·개정 이력

개정번호 | 개정번호 | 개정내용 | 작성자 | 검토자 | 승인자
V.1.0 | 2023.01.25 | 최초 작성 | 박수현, 최태훈 | 박지애 | 전승혁

·

목 차

제1장 데이터 명세 ····························································································· 1

1. 데이터 정보 요약 ···························································································· 1
2. 데이터 포멧 ····································································································· 2
3. 어노테이션 포멧 ································································································ 4
4. 데이터 구성 ····································································································· 5
5. 데이터 통계 ··································································································· 5
6. 원시데이터 특성 ······························································································ 7
7. 기타 정보 ······································································································· 7

제2장 데이터 구축 ··························································································· 13

1. 데이터 구축 개요 ·························································································· 13
2. 임무 정의 ······································································································· 15
3. 획득(수집) ······································································································· 17
4. 정제 ················································································································ 21
5. 가공(라벨링) ··································································································· 24
6. 검사 ·················································································································· 42
7. 학습 모델 ········································································································· 46

제3장 데이터 활용 ··························································································· 48

1. 데이터 활용 ··································································································· 48
2. 응용 서비스 ··································································································· 48
3. 응용 서비스 개발 ·························································································· 48
4. 기술 지원 ····································································································· 48

- 1 -

## 제1장 데이터 명세 정보

### 1. 데이터 정보 요약

데이터 명 | 생활폐기물 데이터 활용-환류
활용 분야 | 생활폐기물 분리수거 자동화
데이터 요약 | 이물질과 다중포장재의 유무에 따른 환경별 캔, 비닐, 종이, 종이팩, 패트, 유리병, 플라스틱, 스티로 폼,건 전지 총 9가지로 분류 정의된 AI 학습용 데이터셋
데이터 출처 | 서르에서 직접 개발한 재활용 선별장 인식장비, 실내형 분류기 , 어플리케이션을 통해 직접 수집
| 데이터 구축 규모 | 이미지 551,562장
| | Ÿ 다양성(통계) : 수집 방법별 수량
| 목표 | 수량
재활용 선별장 | 200,000 | 222,835
실내형 분류기 | 100,000 | 127,844
어플리케이션 | 200,000 | 200,883
Total | 500,000 | 551,562

데이터 통계
데이터 분포

(충분성, 균등성, 편향성 여부
확인)

Ÿ 다양성(요건) : 학습요건을 충족 (클래스 최소수량 8,000)

Label | label_count
c_1 | 64,087
c_1_01 | 10,466
c_2_01 | 16,116
c_2_02 | 13,531
c_2_02_01 | 21,673
c_3 | 68,258
c_3_01 | 14,646
c_4_01_01 | 12,853
c_4_01_02 | 8,551
c_4_02_01_01 | 12,529
c_4_02_01_02 | 9,153
c_4_02_02_01 | 8,832
c_4_02_02_02 | 9,378
c_4_02_03_01 | 11,036
c_4_02_03_02 | 9,490
c_4_03 | 10,480
c_4_03_01 | 11,521
c_5_01 | 282,538
c_5_01_01 | 127,489
c_5_02 | 53,243
c_5_02_01 | 22,964
c_6 | 291,622
c_6_01 | 305,772
c_7 | 89,334
c_7_01 | 14,197
c_8_01 | 10,033
c_8_01_01 | 11,228
c_8_02 | 9,577
c_9 | 23,235
데이터 이력 | 배포 버전 | v1.0
| 개정 이력 | 신규
| 작성자/배포자 | 주식회사 서르

- 2 -

### 2. 데이터 포맷

기본 포맷 : 원천데이터(jpg,jpeg,png) / 라벨링데이터(JSON)

구분 | No | 속성명 | 속성 및 내용
선택 | 1 | objects.id | 라벨링 시 부여되는 이미지당 id
선택 | 2 | objects.class_id | 라벨링 시 부여되는 어노테이션당 id
선택 | 3 | objects.tracking_id | 이미지 번호
필수 | 4 | objects.class_name | 클래스명
필수 | 5 | objects.annotation_type | 어노테이션 타입
필수 | 6 | annotation.coord.x | box의 좌측상단x좌표
필수 | 7 | annotation.coord.y | box의 좌측상단 y 좌표
필수 | 8 | annotation.coord.width | box의 너비
필수 | 9 | annotation.coord.height | box의 높이
선택 | 10 | annotation.meta.z_index | box의 생긴 순서
선택 | 11 | annotation.meta.visible | box의 visible 여부
선택 | 12 | annotation.meta.alpha | 특정 번호
선택 | 13 | annotation.meta.color | box의 색상
선택 | 14 | objects.properties | 객체의 속성
선택 | 15 | categories.properties | box의 속성
필수 | 16 | Image | 이미지 이름
필수 | 17 | Info.PLACE | 실내/실외
필수 | 18 | Info.GPS | GPS 좌표
필수 | 19 | Info.ADDRESS | 주소
필수 | 20 | Info.METHOD | 촬영방법
필수 | 21 | Info.DATE | 촬영날짜 및 시간
필수 | 22 | Info.DAY/NIGHT | 주간/야간
필수 | 23 | Info.DEVICE | 촬영장비
필수 | 24 | Info.BRAND | 촬영브랜드
필수 | 25 | Info.RESOLUTION | 이미지 해상도
필수 | 26 | Info.COLOR | 이미지 컬러값
필수 | 27 | Info.ROTATE | 이미지 회전값
필수 | 28 | Info.EXPOSURE | 이미지 노출값
필수 | 29 | Info.ISO | 이미지 ISO값

- 3 -
| 예시 | 데이터항목 | JSON형식(예시)

폐기물 선별소 이미지 데이터

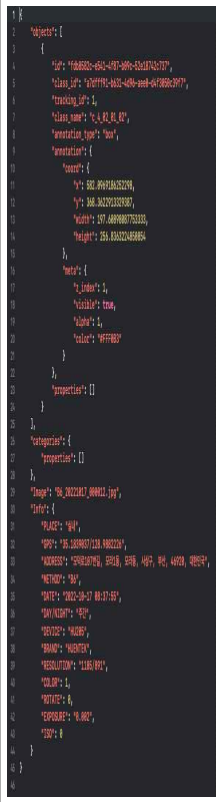
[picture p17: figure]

실내분류기 이미지 데이터

어플리케이션 이미지 데이터

c_1(종이)
c_2_01(종이팩)
c_2_02(종이컵)
c_3(캔류)
c_4_01_02(재사용 유리(소주병+맥주병)) c_4_02_01_02(갈색 유리)
c_4_02_02_02(녹색 유리)
c_4_02_03_02(백색 유리)
c_4_03(기타 유리)
c_5_02(페트)
c_6(플라스틱)
c_7(비닐)
c_1_01(종이+이물질)
c_2_02_01(종이컵+이물질)
c_3_01(캔+이물질)
c_4_03_01(기타유리+이물질)
c_5_01_01(페트+이물질+다중포장재)
c_5_02_01(페트+이물질)
c_6_01(플라스틱+이물질)
c_7_01(비닐+이물질)
c_4_01_01
(재사용유리(소주병+맥주병)+다중포장재)
c_4_02_01_01(갈색유리+다중포장재)
c_4_02_02_01(녹색유리+다중포장재)
c_4_02_03_01(백색유리+다중포장재)
c_5_01(페트+다중포장재)
c_8_01(흰색 스티로폼)
c_8_02(컬러 스티로폼)
c_8_01_01(스티로폼+이물질)
c_9(건전지)

- 4 -
구분 | 획득(수집) 단계 | 정제 단계 | 가공(라벨링) 단계
데이터 구분 | 원시데이터 | 원천데이터 | 최종데이터
데이터 형태 | 동영상, 이미지 | 동영상 -> 이미지 | 이미지 / 가공데이터
데이터 포멧 | 데이터포맷 : 동영상 -> mp4 이미지 -> jpg,jpeg,png | 1280*720 이상, 컬러 | 이미지: jpg,jpeg,png 가공데이터: JSON

### 3. 어노테이션 포맷

구분 | 속성명 | 타입 | 필수 여부 | 설명 | 비고
1 | objects | array | Y
| 1-1 | objects.id | string | N | 라벨링 시 부여되는 이미지당 id
| 1-2 | objects.class_id | string | N | 라벨링 시 부여되는 어노테이션당 id
| 1-3 | objects.tracking_id | number | N | 이미지 번호
| 1-4 | objects.class_name | string | Y | 클래스명
| 1-5 | objects.annotation_type | string | Y | 어노테이션 타입
| 1-6 | objects.annotation | object | Y
| 1-6-1 | annotation[].coord | object | Y
| 1-6-1-1 | annotation[].coord[].x | number | Y | box의 좌측상단x좌표
| 1-6-1-2 | annotation[].coord[].y | number | Y | box의 좌측상단 y 좌표
| 1-6-1-3 | annotation[].coord[].width | number | Y | box의 너비
| 1-6-1-4 | annotation[].coord[].height | number | Y | box의 높이
1-6-2 | | annotation[].meta | object | N
| 1-6-2-1 | annotation[].meta[].z_index | number | N | box의 생긴 순서
| 1-6-2-2 | annotation[].meta[].visible | boolean | N | box의 visible 여부
| 1-6-2-3 | annotation[].meta[].alpha | number | N | 특정 번호
| 1-6-2-4 | annotation[].meta[].color | string | N | box의 색상
1-7 | objects.properties | array | N | 객체의 속성
2 | categories | object | N
| 2-1 | categories.properties | array | N | box의 속성
3 | | Image | string | Y | 이미지 이름
4 | | Info | object | Y
| 4-1 | Info.PLACE | string | Y | 실내/실외
| 4-2 | Info.GPS | string | Y | GPS 좌표
| 4-3 | Info.ADDRESS | string | Y | 주소
| 4-4 | Info.METHOD | string | Y | 촬영방법
| 4-5 | Info.DATE | string | Y | 촬영날짜 및 시간
| 4-6 | Info.DAY/NIGHT | string | Y | 주간/야간
| 4-7 | Info.DEVICE | string | Y | 촬영장비
| 4-8 | Info.BRAND | string | Y | 촬영브랜드
| 4-9 | Info.RESOLUTION | string | Y | 이미지 해상도
| 4-10 | Info.COLOR | number | Y | 이미지 컬러값
| 4-11 | Info.ROTATE | number | Y | 이미지 회전값
| 4-12 | Info.EXPOSURE | string | Y | 이미지 노출값
| 4-13 | Info.ISO | number | Y | 이미지 ISO값

- 5 -

### 4. 데이터 구성

분류1 (데이터 수집 방법) | 분류2 (수집날짜) | 분류 3 (번호) | Format
A1~A9 / B1~B10 / C | ex)20220101 | ex)00001 | jpg,jpeg,png
A1~A9 / B1~B10 / C | ex)20220101 | ex)00001 | json

[생활폐기물 데이터 활용·환류 데이터 파일 구조]

### 5. 데이터 통계

### 5.1 데이터 통계

5.1.1 데이터 구축 규모

- 최종 인공지능 데이터
- 해상도 1280*720이상 이미지 551,562만 장, 어노테이션 json파일 551,562건
- bounding box 및 라벨 부착, 약 160만건의 annotation 수행

[생활폐기물 데이터 활용·환류 데이터 구축 규모 및 형식]

[생활폐기물 데이터 활용·환류 데이터 구축량]

데이터 종류 | 구축 목표 | 어노테이션 구축량 | 데이터 형식 | 데이터 크기
재활용 선별장 | 200,000 | 222,835 | json 파일 | 78GB
실내형 분류기 | 100,000 | 127,844 | | 20GB
어플리케이션 | 200,000 | 200,883 | | 570GB
Total | 500,000 | 551,562 | | -

- 6 -

5.1.2 데이터 분포

NO | 구분 | label | 기준 | label_count
1 | 재활용 | c_1 | 종이 | 64,087
2 | | c_2_01 | 종이팩 | 16,116
3 | | c_2_02 | 종이컵 | 13,531
4 | | c_3 | 캔류 | 68,258
5 | | c_4_01_02 | 재사용 유리 (소주병+맥주병) | 8,551
6 | | c_4_02_01_02 | 갈색 유리 | 9,153
7 | | c_4_02_02_02 | 녹색 유리 | 9,378
8 | | c_4_02_03_02 | 백색 유리 | 9,490
9 | | c_4_03 | 기타 유리 | 10,480
10 | | c_5_02 | 페트 | 53,243
11 | | c_6 | 플라스틱 | 291,622
12 | | c_7 | 비닐 | 89,334
13 | 일반쓰레기 | 이물질 | c_1_01 | 종이 + 이물질 | 10,466
14 | | | c_2_02_01 | 종이컵 + 이물질 | 21,673
15 | | | c_3_01 | 캔 + 이물질 | 14,646
16 | | | c_4_03_01 | 기타유리 + 이물질 | 11,521
17 | | | c_5_01_01 | 페트 + 이물질 + 다중포장재 | 127,489
18 | | | c_5_02_01 | 페트 + 이물질 | 22,964
19 | | | c_6_01 | 플라스틱 + 이물질 | 305,772
20 | | | c_7_01 | 비닐 + 이물질 | 14,197
21 | | 다중포장재 | c_4_01_01 | 재사용 유리 (소주병+맥주병) + 다중포장재 | 12,853
22 | | | c_4_02_01_01 | 갈색 유리 + 다중포장재 | 12,529
23 | | | c_4_02_02_01 | 녹색 유리 + 다중포장재 | 8,832
24 | | | c_4_02_03_01 | 백색 유리 + 다중포장재 | 11,036
25 | | | c_5_01 | 페트 + 다중포장재 | 282,538
26 | 별도 | | c_8_01 | 흰색 스티로폼 | 10,033
27 | | | c_8_02 | 컬러 스티로폼 | 9,577
28 | | | c_8_01_01 | 스티로폼 + 이물질 | 11,228
29 | | | c_9 | 건전지 | 23,235
| 총합 | | | | 1553,832

- 7 -

### 6. 원시데이터 특성

6.1.1 대상분류
- 재활용 선별장 : 선별장 컨베이어 벨트 위에서 촬영된 영상
- 실내형 분류기 : 실내형 분류기에 투입되어진 오브젝트를 촬영한 이미지
- 어플리케이션 : 어플리케이션로 수집한 실생활의 다양한 환경에서 촬영된 오브젝트 이미지

6.1.2 제약조건
- 제약없음(unconstrained) - 지역별 재활용 선별장 9곳을 방문하여 촬영기기 설치 후, 선별장 컨베이어 벨트를 지나가는 오

브젝트를 촬영하여 원시데이터를 수집
- 일부 제약있음(semi-constrained) - 실내형 분류기 및 어플리케이션을 통한 오브젝트 수집시, 재활용 class 기준 29가지에 해당하

는 객체 위주로 원시데이터를 수집하였음 클래스 이외의 재활용 오브젝트가 발견될시, 그 이 미지는 제외하고 수집하였음

6.1.3 속성

No | 속성명 | 항목 설명 | Type | 필수여부 | 예시
1 | PLACE | 촬영 장소 실 내*외 구분 | string | Y | 실내
2 | GPS | 촬영 장소의 GPS 좌표값 | string | Y | 36.18211179/128.477652 799
3 | ADDRESS | 촬영 장소의 주소 | string | Y | 대한민국 39159 경상북도 구미시 송백로
4 | METHOD | 촬영 방법 | string | Y | A1C
5 | DATE | 촬영 날짜 | string | Y | 2022-08-18
6 | DAY/NIGHT | 촬영 당시 주*야간 구분 | string | Y | 주간
7 | DEVICE | 촬영장비 | string | Y | HU205
8 | BRAND | 촬영장비 브랜드명 | string | Y | HUENTEK
9 | RESOLUTION | 이미지해상도 | string | Y | 1847/883
10 | COLOR | 이미지 컬러값 | number | Y | 1
11 | ROTATE | 이미지 회전값 | number | Y | 0
12 | EXPOSURE | 이미지 노출값 | string | Y | 0.002
13 | ISO | ISO | number | Y | 0

### 7. 기타 정보

7.1.1 포괄성
- 전국에 고르게 분포(선별장 9곳) - 구미, 김해, 광명, 남해, 부산(진구), 양산, 창녕, 경주, 연천의 데이터를 수집함. 대도시, 중소도

시, 농어촌 등 고르게 분포한 지역 선별장 데이터 수집하여 데이터셋 밸런스를 확보함.

- 8 -
- 선별장 조사
- 2022년 3월 22일 김해시 선별소를 방문하여 생활폐기물 분류 현황을 확인한 결과, 현재 AI 허 브에서 공개된 데이터로를 활용한 인공지능 모델로는 처리하기 어려운 수준의 개체 겹침, 흔 들림, 떨어짐, 컨베이터 속도, 현장 조명 등을 확인함, 실제 현장 상황을 반영한 데이터 수집 필요성을 확인하였음. 전국에 고루 분포된 구미, 김해, 광명, 남해, 부산(진구), 양산, 창녕, 경주, 연천 지역을 차례로 방문하여 다양한 생활 폐기물 데이터를 수집할 수 있었음

7.1.2 독립성 법률계
- 재활용가능자원의 분리수거 등에 관한 지침[시행 2022. 12. 1.] [환경부훈령 제1568호, 2022.
12. 1., 일부개정]의 분리수거대상 재활용가능자원의 품목 및 분리배출요령을 일부 참고하여 재활용 class기준을 정함

7.1.3 유의사항

- 파급효과
- 재활용가능인공지능 재활용품 선별 및 분류 AI 알고리즘을 실제 생활폐기물 선별 및 분류기에 적용할수 있도록 알고리즘의 수정 및 보완이 용이하게 제공될 수 있음
- 건축물의 실내 공간에 실내형 선별기 설치를 통해 생활계 재활용품의 원활한 분리배출을 이끌 어냄 - 올바른 재활용품 분리배출에 대한 교육과 학습을 제공하는 AI 기반 분리배출 교육 플랫폼 서

비스로 응용 가능하며, 학습모델과 튜토리얼 서비스를 VR/AR 확대하여 교육용으로 개발이 가
- 생활폐기물 수거부터 처리까지 인공지능 무인 기기를 활용 범위를 고려한 스마트 시티 설계에 도움이 될 수 있으며, IoT 기술 등과 결합하여 실시간 생활폐기물 처리 방안을 도출할 수 있음
- 인공지능을 공부하는 개인부터 사업화를 시도하는 기업까지 누구나 사용 가능한 데이터셋을 개발하여생활폐기물 분야의 연구 활성화를 지원함
- 데이터 활용 시 유의사항
- 내부 메뉴얼에 따른 기준(오염물, 복합재질의 재활용품도 포함됨)으로 분류된 재활용품 class이 므로 분리수거대상 재활용가능자원의 품목 및 분리배출요령 등, 실제 공고되는 지침과는 다소 차이가 있을 수 있음

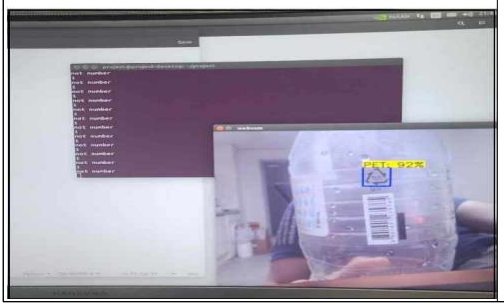
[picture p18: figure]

- 9 -

7.1.4 관련 연구

- 국내 연구 동향
연도 | 방법론 | 데이터 | 연구내용 | 연구자
2021 | YOLO | PET 115장, HDPE 100장, PP 98장 | 플라스틱 재활용을 위한 YOLO기반의 자동 분류시스템 | 김용준, 조태욱, 박형근
2021 | 머신러닝 | cardboard 403개, glass 501개, metal 410개, paper 594개, plastic 482개, trash 137개 | 분리수거를 위한 리사이클링 봇 이미지 데이터 학습모델 구현 | 노유정, 신복숙
2021 | YOLOv4 | 캔 5,117장, 페트병 5,030장, 펜 5,081장, 마우스 4,881장, 종이박스 5020장, 클립 5,285장, 열쇠 5,046장, 비닐 5,118장, 일회용 커피 포장지 5,269장 | YOLOv4 와 라즈베리파이 기반 쓰레기 분리배출 자동화 시스템 | 김기현, 유호연, 이효진, 변혜원
- 김용준, 조태욱, 박형근(2021)은 실시간 물체 인식 알고리즘인 YOLO (You Only Look Once)를 이용하여 플라스틱의 종류를 자동으로 분류하는 시스템을 구현 연구 추진
- 시스템은 Nvidia 사에서 만든 딥러닝, 컴퓨터비전용 소형 컴퓨터인 Jetson Nano에 YOLO를 이 용하여 플라스틱 분리배출 마크를 인식할 수 있도록 훈련시킨 모델 탑재
- 웹캠을 이용해서 플라스틱 쓰레기의 분리배출 마크를 PET, HDPE, PP 세종류로 인식하고 모터 를 조절하여 종류에 따라 분류
YOLO를 이용한 객체검출 (PET) | 하드웨어 설계도(Hardware design)
- 노유정, 신복숙(2021)은 분리수거를 위한 리사이클링 봇 이미지데이터 학습모델 구현을 연구하 였으며, 재활용품 분리배출에 대한 교육과 학습을 제공하는 AI 기반 분리배출 교육 플랫폼 서 비스를 기획하고, 재활용품을 인식하고 판단하는 리사이클링 봇 이미지데이터 학습모델 구현함
- 리사이클링 봇은 대량으로 수집되는 이미지데이터를 이용하여 인식 판단하기 위한 AI 학습모 델을 적용하고 실험을 진행하여 결과를 확인함

- 10 -

[리사이클링 봇 기능과 서비스 구성]

- 김기현, 유호연, 이효진, 변혜원 (2021)은 YOLO 모델과 라즈베리파이를 이용하여 재활용 쓰레기 를 9종류의 클래스(캔, 페트병, 펜, 마우스, 종이박스, 클립, 열쇠, 비닐, 일회용 커피 포장지)로 분리배출하는 새로운 자동화 시스템을 제안함
- YOLOv4 모델을 이용한 쓰레기 검출과 분류에서는 자체 생성한 데이터 셋, 크롤링한 데이터 셋

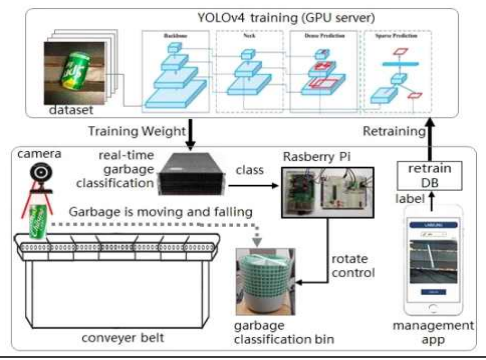
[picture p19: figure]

과 공개 데이터 셋으로 재활용 쓰레기 데이터 셋을 구축하고, 모델 파라메터 최적화를 통해 YOLOv4 모델의 실시간 성능을 유지하면서도 정확도를 90% 이상으로 향상시킴

시스템 개요 | 종류별 재활용 쓰레기 이미지
- 해외 연구 동향

- 11 -
연도 | 알고리즘 | 산업 | 관련 기술 | 이미지 수량 | 결과 | 연구자
2019 | Regional Convolutional Neural Network (R-CNN) | Food waste sorting | Image processing | 7200 | Faster regional CNN flat method model reached mean average precision of 74.1% | Sousa et al.
2019 | Deep Neural Network (DNN) | Plastic waste | Image Processing, Raspberry Pi Controller Board/Sensor Sorting Waste | 1749 | Accuracy of 98% | Mwangi & Mokoena
2019 | Convolutional Neural Network(CNN) | waste Solid | Waste Classification | 1989 | Accuracy of 87% | Adedeji & Wang
2019 | Support Vector Machine (SVM) | Bottle recycling | Image Processing | 1446 | Accuracy of 94.7% | Wang et al.
2018 | Convolutional Neural Network(CNN) | Recycling | Image Processing | 2400 | Accuracy around 93% | Costa et al.
2018 | Convolutional Neural Network (CNN) | Bottle recycling | Raspberry Pi Controller Board/ SensorSortingWaste | 300 | Accuracy is 80–100%, but machinetakes7–9s.torecog-nizebottleineachcase | Nalepa & Kawulok
2018 | Convolutional Neural Network (CNN) | Constructi on | Waste Classification | 74 | Max and min relative errors of 18.93% and less than 10% error 0.01%, respectively; roughly 85% of data has | Deng et al.
2018 | Convolutional Neural Network (CNN) | waste Solid | Image Processing | 500 | Accuracy of 84% is attained | Adedeji & Wang
- Sousa et al.(2019)은 음식물 트레이의 폐기물 감지 및 분류를 위한 계층적 딥 러닝 접근방식을 제안함. 제안된 2단계 접근방식은 최근의 물체 검출기(더 빠른 R-CNN)의 장점을 유지하며, 더 높은 경계 상자에서 분류 작업을 지원한다는 점을 도출

[음식물 객체 인식 예시]

- Mwangi & Mokoena (2019)은 재활용을 위한 페트병의 상태를 검출하는 메커니즘 확립을 목적 으로 라즈베리 파이 카메라로 촬영된 이미지는 총 1,749장으로 씰, 캡, 씰&캡, 노씰, 캡&컨텐츠 의 4가지 클래스로 분류함
- 딥 러닝 테크놀로지(SqueezeNet)를 사용하여 페트병 이미지를 훈련하였으며, 병 상태를 인식하 여 98%의 정확도를 달성함. 인텔 CPU를 사용한 예측당 0.018~0.022초의 지연을 보인 반면, Rasberry Pi에서는 예측 성능은 Intel CPU보다 5~10배 느리고 예측당 지연은 0.1~0.25초로 나

타남

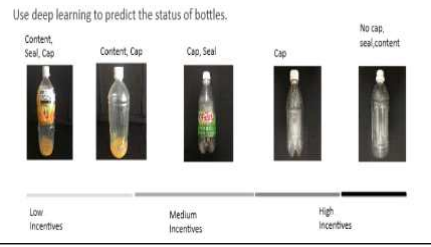
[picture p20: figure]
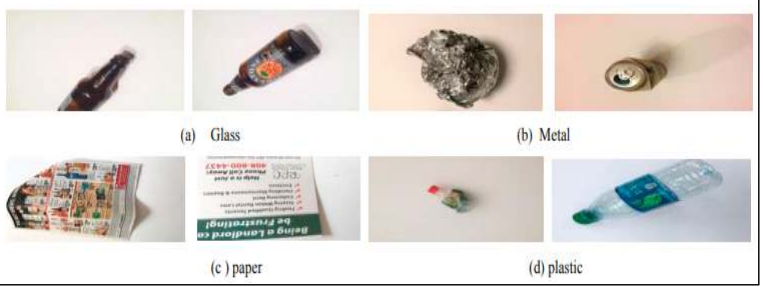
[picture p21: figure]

- 12 -
PET 상태 | 시스템 개념도

[객체 인식 예시]

- Adedeji & Wang (2019)은 폐기물 인식 프로세스를 간소화하기 위해 기계학습 도구이자 추출기 역할을 하는 컨볼루션 뉴럴 네트워크 모델과 서포트 벡터 머신(SVM)을 사용하여 개발된 지능형 폐기물 분류 시스템을 제안함
- 유리, 금속, 종이, 플라스틱 등의 업/타입 제안된 시스템은 휴지통 이미지 데이터 세트에서 테스 트 되었으며, 데이터 세트에서 87%의 정확도를 달성함

주요 분석 이미지

- 13 -

## 제2장 데이터 구축

### 1. 데이터 구축 개요

가. 구축 배경 및 목적

- 데이터 구축 배경 및 목적
① 자체 제품 및 서비스를 활용하여 재수집된 데이터를 통해 공개 데이터의 한계점 해소 ② 생활폐기물의 원활한 분리 배출을 위한 오염물 및 다중포장재 데이터 확보 문제 해소 ③ 재활용 선별소 단위에서 다중 객체 인식 및 복잡한 데이터 확보 문제 해소
- 데이터 구축 필요성
① 기존 공개 데이터는 단순 객체 인식 및 통제된 배경에서 데이터가 수집되어 실제 현장에서 적용하기 어려우며, 실제 제품 및 서비스의 성능에 충족되지 않음
② 이물질 및 오염물에 대한 데이터는 일반 쓰레기로 구분되어 있어 재활용 데이터로서 의미가 상실되어 새로운 데이터 추가가 필요
③ 다중포장재 재활용품 데이터가 확보되어 있지 않음. 2022년 1월 1일 이후 분리배출 표시 제 도로 인하여 다중포장재 데이터 반영의 필요함
④ 다중 객체 데이터 미구축 및 AI 모델의 한계점 발견되어 인공지능 모형의 성능 저하가 발생 할 수 있음. 따라서 다중 객체가 고려된 데이터 구축이 필요
⑤ 환경부의 생활계에서 발생하는 재활용가능자원의 올바른 분리배출을 촉진하기 위하여 재활용가능 자원의 분리배출 방법 및 요령에 대한 세분화한 지침이 반영된 데이터 구축 필요

나. 구축 데이터 명세

- 데이터 구축 프로세스
- 재활용품 분류 데이터 수집 요약
주요내용 | 데이터 분류 | 데이터 수집 방법 | 데이터 구축량 | 총 구축량 | 클 래 스 | 데이터 형식 | Annotatio n Type
대용량 분류기에서 수집되는 영상 | 영상 데이터 | 선별장 촬영 장비 설치 후 촬영 | 222,835 | 551,562 | 29 개 | avi,mp4, mpg | Bounding Box
재활용 어플리케이션에서 수집되는 이미지 | 이미지 데이터 | 사용자가 직접 촬영 | 200,883 | | | jpg, jepg, png
실내용 분류기에서 수집되는 이미지 | | 분류기에 투입되어진 오브젝트 촬영 | 127,844

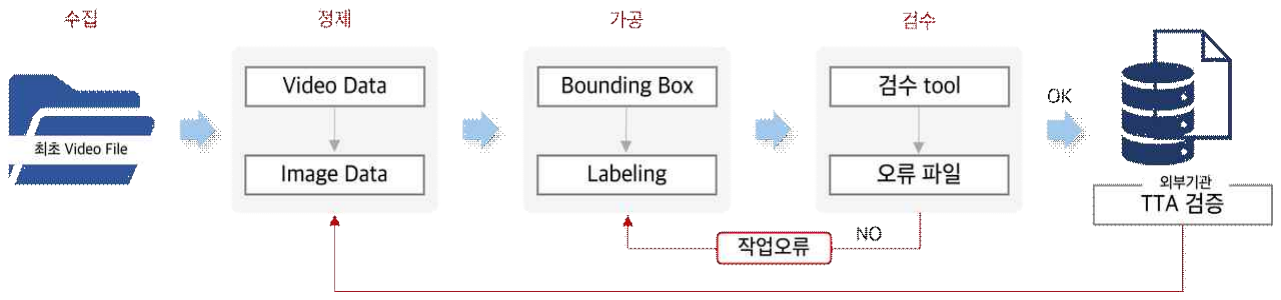
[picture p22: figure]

- 14 -
- 원시 데이터 내용
- 일반 재활용 데이터(12개 클래스) : 종이, 종이팩(우유팩, 주스팩, 두유팩), 종이팩(종이컵), 캔류, 유리 (소주병 + 맥주병), 유리(갈색), 유리(녹색), 유리(백색), 유리(기타), 페트(무색), 플라스틱, 비닐
- 이물질 데이터(8개 클래스) : 종이 + 이물질, 종이컵 + 이물질, 캔 + 이물질, 페트(무색)+이물질, 페트(무색)+부속품+이물질, 플라스틱 + 이물질, 비닐 + 이물질, 스티로폼+이물질
- 복합재질 데이터(6개 클래스) : 유리(소주병 + 맥주병) + 부속품, 유리(갈색)+부속품, 유리(녹색)+ 부속품, 유리(백색)+부속품, 유리(기타)+부속품, 페트(무색)+부속품
- 추가 3개 클래스 : 스티로폼(흰색), 스티로폼(컬러), 건전지

다. 인공지능 학습용 데이터 구축 환경
- 클라우드 서버 중심 : 코로나 상황 고려 / 크라우드소싱 업무 환경 / 재택근무 환경
- 데이터 보안 : 물리적/ 시스템적 보안 환경 구축 - 데이터 정제/가공/검증 : 데이터 전문 가공/평가 시스템 활용 및 교육을 수료한 크라우드소싱 인

력/인하우스 인력을 위한 사무실 운영

라. 인공지능 학습용 데이터 구축 방법
- 데이터셋 구축 : 이미지/영상 데이터 → 이미지 추출 → Labeling → 검사 → 학습데이터 제공
- Annotation : 이미지에 대해 naming annotation 수행
- 영상 데이터 이미지화 및 넘버링 : Python의 OpenCV를 이용하여 영상 데이터를 1초당 1장의 이미지 데이터화 작업을 진행하여 총 245,000장으로 이미지화를 진행

마. 인공지능 학습용 데이터 검사

- 데이터 획득부터 정제, 가공(라벨링), AI학습모델을 위한 검사 절차를 수립

- 15 -

### 2. 임무 정의

2.1 임무 정의

- 재수집 데이터를 활용한 생활폐기물 영상/이미지 데이터의 활용도 향상
- 자체 개발한 제품 및 서비스를 활용한 재수집 데이터를 통해 현장감이 반영된 생활폐기물 데 이터를 확보하고, 데이터 확산 및 환류함으로써 재활용 산업발전에 기여함
- 폐기물 선별소 9개(구미, 김해, 광명, 남해, 부산(진구), 양산, 창녕, 경주, 연천)를 대상으로 활용 도 높은 영상/이미지 데이터를 수집하여 데이터 활용성을 높임
- 종이, 종이팩, 캔류, 유리(재사용 (소주병 + 맥주병), 재활용, 기타), 페트, 플라스틱, 비닐류, 스 티로폼, 건전지, 일반쓰레기(이물질과 오염물, 복합재질) 등 29개의 클래스에 50만장의 고품질 원시데이터 획득하여, 현장에 필요한 데이터를 공급
- 생활폐기물 및 재활용 분야의 범용성 있는 AI 모델을 개발하여 상대적으로 디지털 전환이 늦 은 재활용 폐기물 산업의 디지털화를 추진함
- 고품질의 라벨링 데이터 확보
- 생활폐기물과 재활용품 정보가 결합된 다양한 라벨링 데이터를 확보하고 인공지능 개발에 있 어서 의미 있는 정보를 전달
- 폐기물 전문가의 철저한 영상/이미지 검수를 수행하고 데이터 품질을 확보 - 영상/이미지 인식 영역에서 나타날 수 있는 모든 생활폐기물을 분류한 29개 클라스 어노테이

션을 통한 기존 공개데이터 보완 및 개선에 기여

- 재수집된 생활폐기물의 인식 및 분류 인공지능 모델 개발
- 재활용품 중 인공지능 알고리즘을 결합하여, 가장 정확하고 의미 있는 결과를 낼 수 있는 정보 를 추출하고 실용적인 인공지능 모델 개발에 기여
- 생활폐기물과 재활용품을 구별하고 인식할 수 있는 알고리즘이 결합된 데이터베이스를 구축하 여, 이것들을 판별하는 기술개발 및 연구의 즉각적인 진행에 기여
- 궁극적으로 생활폐기물 데이터 활용ㆍ환류는 글로벌 기후위기 대응과 관련 산업의 디지털화 촉 진의 일환으로 생활폐기물과 관련된 인공지능 시스템, 솔루션, 로봇 등 기술적 활용도를 높이는 것을 목표함

가. 활용대상

- 생활폐기물 선별 기계장치 개발사
- 인공지능 재활용품 선별 및 분류 AI 알고리즘을 실제 생활폐기물 선별 및 분류기에 적용할 수 있도록 알고리즘의 수정 및 보완이 용이하게 제공될 예정
- 폐기물 선별장
- 대용량 데이터를 통해 생활폐기물 선별의 명확한 기준을 제공해 줄 수 있으며, 향후 인공지능 선별기 도입에 있어서 요구되는 기술 수준을 가늠해 볼 수 있음
- 스마트 시티 설계 및 정책 입안
- 생활폐기물 수거부터 처리까지 인공지능 무인 기기를 활용 범위를 고려한 스마트 시티 설계에 도움이

- 16 -

될 수 있으며, IoT 기술 등과 결합하여 실시간 생활폐기물 처리 방안을 도출할 수 있음

- 생활폐기물 데이터 연구자
- 인공지능을 공부하는 개인부터 사업화를 시도하는 기업까지 누구나 사용 가능한 데이터셋을 개발하여 생활폐기물 분야의 연구 활성화를 지원함

나. 기대효과

- 기술적 측면
- 생활폐기물의 다양한 객체 검출 및 분류에 대한 원천기술 확보로 기기 장치, 알고리즘 등 외국 기술의 국산화 및 산업 확산 용이
- 요소기술인 객체 검출 및 분류 기술은 딥러닝 분야에서 다양하게 연구가 시도되고 있는 분야 로 성능의 알고리즘 개발을 통해 각 요소 기술별로 타 분야에 적용 가능
- 생활폐기물의 분리 방법을 알려주거나 직접 분류해주는 로봇 등에 적용가능한 다양한 어플리 케이션 개발 가능
- 생활폐기물 분류뿐만 아니라 공항 검색대, 제조 및 생산공정 등 분류 기술을 필요로 하는 관련 산업 분야로의 확장 기대
- 사회적 측면
- 한국정보화진흥원의 폐쇄망에 데이터를 저장하고, 적절한 승인을 받은 개발사에게 필요한 데이 터의 사용이 가능하도록하여 기술의 사회적 확산에 기여할 수 있음
- 응용된 생활폐기물 분류 기술은 올바른 재활용을 통해 쓰레기 매립 문제 및 환경 문제를 개선 할 수 있음
- AI 기반의 생활폐기물 검출 및 분류 기술로 국가 경쟁력 확보 가능
- 경제적 측면
- 응용 기술 및 기계 장치 상용화로 자동화된 생활폐기물 분리배출이 가능하며, 재활용률 증가로 인하여 사회적인 비용이 감소
- 인공지능을 활용한 정확한 생활폐기물 분류 및 선별은 폐기물 배출량 감소와 재활용품 수입 감소에 긍정적인 영향을 미칠 수 있음
- 폐기물 자동분류를 목표로 하는 기업의 기술 개발, 기술이전, 사업화 활성화로 인한 경제적 가 치를 창출 할 수 있음

2.2 데이터 구축 유의사항

본 과제는 생활 폐기물 영상을 촬영하고 직접 촬영한 이미지를 수집하는 과정에서 실 생활 폐기물 에서 발견되는 개인정보 노출과 오브젝트에 반사되어 나타나는 초상권 문제가 발생 할 수 있다 본 과제의 수집뿐만 아니라 가공 및 검수에 참여하는 참여자 또한 데이터 속 개인정보 보호 문제와 관 련된 위험에 노출될 수 있다

- 대처 방안
1) 저작권협회, 개인정보보호위원회 규정 확인 후 지침 수립 완료
2) 촬영 전 촬영 대상자에게 본 과제의 목적, 개요, 개인 정보 보호 정책에 대한 충분히 설명한다.

- 17 -
3) 촬영 대상자는 개인정보보호법에 의거하여 법률전문가들이 검토하고 추가로 작업에 참여하는 모든 사람들의 개인정보보호법 (수집/보관/3자이용) 및 저작권/지적재산권에 대한 동의 (초상권/ 재산 권 사용동의, 저작권/2차저작권 허용 동의) 진행함

### 3. 획득(수집)

3.1 원시데이터 선정

1) 재활용품 분류 및 선별 데이터

Ÿ 재활용품 분류 데이터 수집 요약

주요내용 | 데이터 분류 | 데이터 수집 방법 | 데이터 구축량 | 총 구축량 | 클래스 | 데이터 형식 | Annotation Type
대용량 분류기에서 수집되는 영상 | 영상 데이터 | 선별장 촬영 장비 설치 후 촬영 | 222,835장 | 551,562장 | 29개 | avi,mp4, mpg | Bounding Box
재활용 어플리케이션에서 수집되는 이미지 | 이미지 데이터 | 사용자가 직접 촬영 | 200,883장 | | | jpg, jepg, png
실내용 분류기에서 수집되는 이미지 | | 분류기에 투입되어진 오브젝트 촬영 | 127,844장

Ÿ 원시 데이터 내용
- 일반 재활용 데이터(12개 클래스) : 종이, 종이팩(우유팩, 주스팩, 두유팩), 종이팩(종이컵), 캔류, 유리 (소주 병 + 맥주병), 유리(갈색), 유리(녹색), 유리(백색), 유리(기타), 페트(무색), 플라스틱, 비닐
- 이물질 데이터(8개 클래스) : 종이 + 이물질, 종이컵 + 이물질, 캔 + 이물질, 페트(무색)+이물질, 페트(무색)+부속품+이물질, 플라스틱 + 이물질, 비닐 + 이물질, 스티로폼+이물질
- 복합재질 데이터(6개 클래스) : 유리(소주병 + 맥주병) + 부속품, 유리(갈색)+부속품, 유리(녹 색)+부속품, 유리(백색)+부속품, 유리(기타)+부속품, 페트(무색)+부속품
- 추가 3개 클래스 : 스티로폼(흰색), 스티로폼(컬러), 건전지

Ÿ 원시 데이터 수집 장소
- 어플리케이션 : 구글 앱스토어를 활용한 일반 사용자 확보 및 인식 데이터 수집
- 실내용 분류기 : 부산 패스파인더 등 건물 내부에 설치된 재활용품 분류 장치를 통해 실제 데 이터 수집
- 대용량 선별기 : 구미, 김해, 광명, 남해, 부산(진구), 양산, 창녕, 경주, 연천 등 공공 생활폐기 물 선별소 9곳에서 영상 데이터 수집

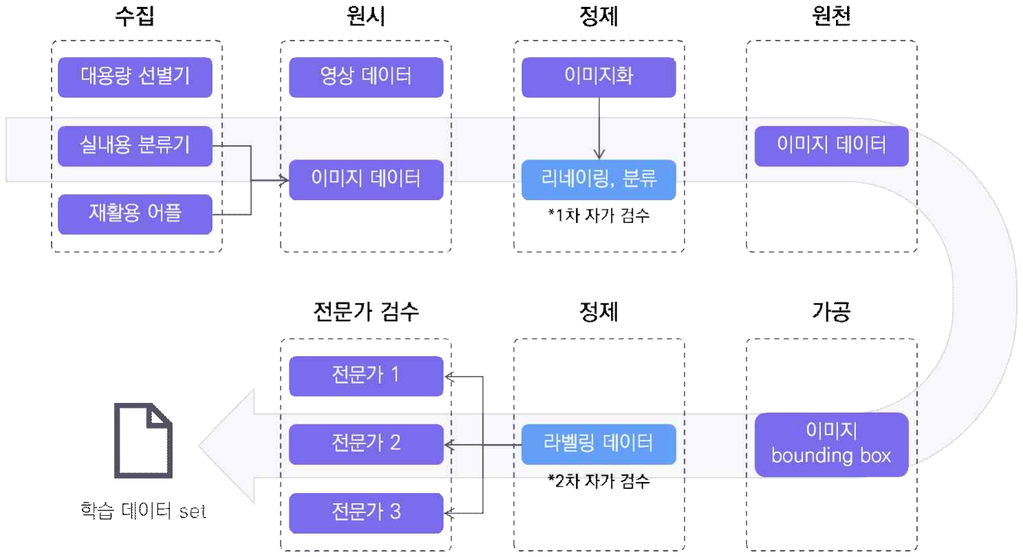
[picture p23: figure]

- 18 -

Ÿ 구축 예정 AI 학습 데이터셋
- 50만장 이상의 재활용품 이미지 및 영상 데이터
- 일반 재활용, 이물질, 복합 재질(부속품 등)을 고려하여 데이터 수집
- 재활용(12개 클래스), 일반쓰레기[이물질과 오염물, 복합재질](13개 클래스), 추가(4개 클래스)로 구분하여 총 29개 클래스당 최소 8천장 데이터 수집
- 종이, 종이팩, 캔류, 유리(재사용 (소주병 + 맥주병), 재활용, 기타), 페트, 플라스틱, 비닐류, 스티로폼, 건 전지, 일반쓰레기[이물질과 오염물, 복합재질]를 포함한 전체 환경부 기준 반영 데이터
- 폐기물 선별 및 관련 분야 전문가를 섭외를 통한 전체 검수 진행

3.2 획득(수집) 절차

Ÿ 재활용 선별장 데이터 수집 방법

1. 데이터 수집시 방문 선별장에 촬영장비를 설치. (9개의 선별소)
2. 각 선별장에 1개의 촬영장비가 투입되어 5시간씩(1~3회)수집 진행. 3. 1개의 촬영장비에는 카메라 3개가 있음. 4. 영상으로 촬영 후 이미지추출. Ÿ 실내형 분류기 데이터 수집 방법

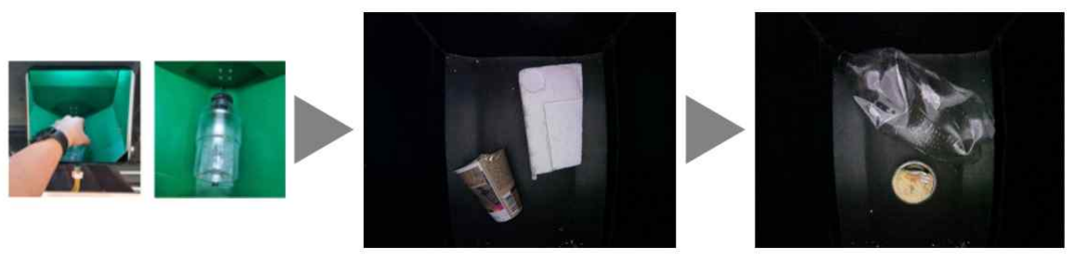
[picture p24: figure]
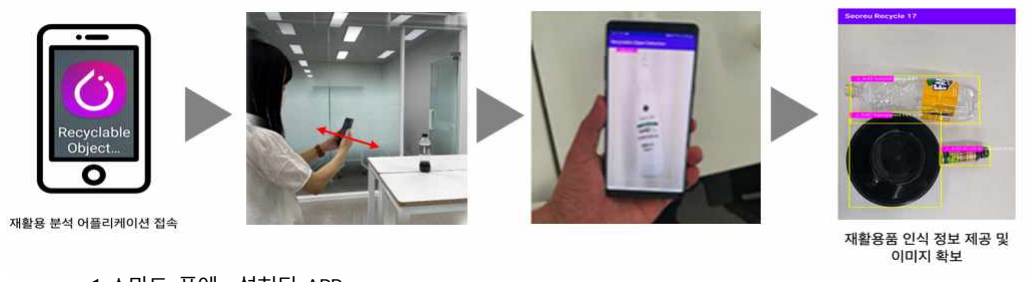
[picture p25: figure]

- 19 -

1.인공지능을 활용한 재활용 분류 기기. 2.기기 내 객체 인식존을 활용 이미지 촬영. 3.기기 당 카메라 1개가 있음. 4.이미지 촬영 환경은 동일함.(조명,및 공간”인식함”)

Ÿ 어플리케이션 데이터 수집 방법

1.스마트 폰에 설치된 APP
2.APP를 실행하여 이미지를 촬영. 3.스마트 폰 카메라 설정으로 환경을 셋팅함. 4.화면에 9등분 격자의 중앙격자가 들어가도록 이미지를 촬영

3.3 획득(수집) 기준

| 분류 | 수량 | 총 수량
데이터 수량 | 이미지/ 영상 데이터 | 재활용 선별장 | 222,835장 | 551,562장
| | 실내형 분류기 | 127,844장
| | 어플리케이션 | 200,883장
해상도 | 최소 1920*1080 PX이상 4032*3024 이하
거리 | - 촬영시 표준거리는 객체가 화면 면적의 5% 이상이 되거나, 객체의 길이가 화면의 가로 또는 세로 중 하나가 30%이상의 비율이 되는 거리 - 원거리 영상 데이터의 경우 객체와의 거리가 1,000mm는 이상, 일반거리 영상 데이터의 경우 객체와의 거리는 700mm~800mm
구도 | 원거리 1장, 정면, 위, 아래 등 다양한 각도

촬영 시간

상용 제품(실내용) 및 서비스(어플리케이션)로 상시 촬영 진행(서버 자동 저장) | 주/야 상황
실제 분류장(대용량)에서 작업하는 동안 촬영 진행 | 반영

- 20 -

◯ 재활용 어플리케이션
- 휴대폰 카메라
- 데이터 수집 : 어플리케이션 사용자가 직접 촬영한 이미지 수집

◯ 실내형 분류기
- 10 FPS/ 1280X720 성능 카메라
- 데이터 수집 : 실내 환경에서 사용자가 직접 넣은 물체를 촬영한 이미지 수집

◯ 대용량 분류기
- 데이터 제공 업체: 전국 대용량 분류기가 설치된 재활용 선별 업체 10곳
- 30 FPS/ 1280X720 성능 카메라
- 데이터 수집 : 재활용 선별 업체 작업장에서 대용량 분류기가 분류를 위해 촬영하는 영상 수집

- 21 -
데이터수집방법 | 날짜 | 번호
A(어플리케이션) | yyyymmdd | number
B(실내용 분류기)
C(대용량 분류기)

파일명 구성요소(파라메터) 별 입력 범위

3.4 획득(수집) 도구

가. 데이터 수집 도구

Ÿ 재활용 선별장 촬영 장비
Ÿ 분류기에 설치되어있는 촬영용 카메라
Ÿ 어플리케이션 (개인 휴대폰 카메라)

나. 데이터 저장 방안

Ÿ 대용량 분류기 영상 데이터
- 촬영된 분류장과 촬영된 날짜별 폴더 이름 지정
- 일정한 주기별로 분류장 담당자가 업로드 및 보관 진행 Ÿ 실내용 분류기 및 재활용 어플리케이션
- 자체 서버를 구축하여 분류기와 어플리케이션에서 나오는 이미지 데이터 저장

다. 데이터 관리 방안

Ÿ 데이터 관리 방안
- 실제 분류장의 컨베이어 벨트 위 고정된 환경에서 진행된 영상데이터를 수집함으로써 고품질의 데이터 생성
- 데이터 담당자가 주차별 데이터 밸런스 확인 및 성능을 테스트하여 성능 미흡부분 추가 학습

### 4. 정제

4.1 원천데이터 규모

◯ 정제 담당 기업 - ㈜서르
◯ 원천데이터 유형
⓵ 텍스트 | ⓶ 이미지 | ⓷ 비디오 | ⓸ 오디오 | ⓹ 기타
□ | ■ | □ | □ | □

◯ 원천데이터 포맷

원시
데이터

원천
데이터 | 항목 | 포맷 | 비고

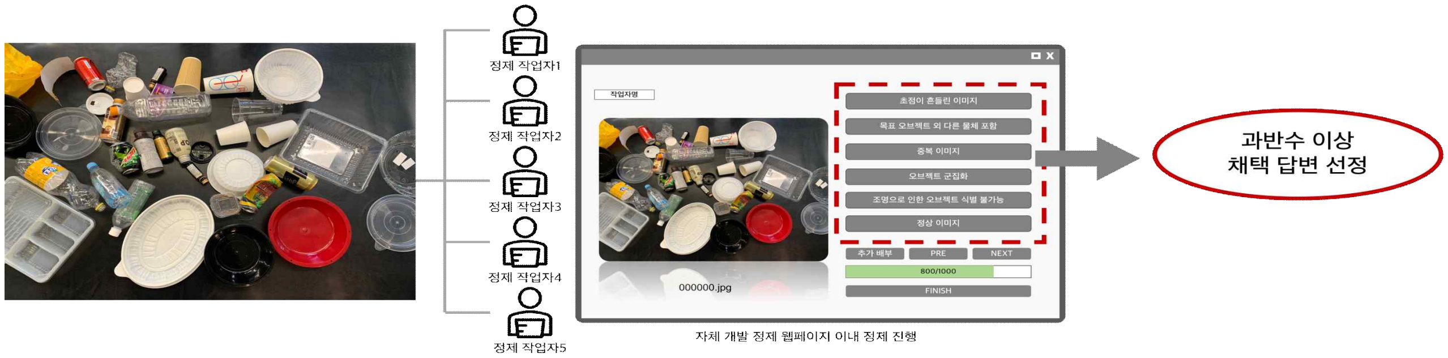
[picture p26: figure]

- 22 -

◯ 영상 데이터 (대용량 분류기)

수집 데이터 | 분할 프레임 | 정제 후 수량
영상 데이터 | 60FPS | 227,000장

◯ 이미지 데이터 (어플 & 실내형 분류기)

수집 데이터 | 단위 | 정제 후 수량
이미지 데이터 | 장 | 391,000장

3.1.5 작업 종류

⓵ 중복제거 | ⓶ 데이터 자르기 | ⓷ 비식별화 | ⓸ OCR 인식 | ⓹ 기타
■ | ■ | □ | □ | ■

4.2 정제 절차
◯ 정제 구조도

영상
데이터

이미지
데이터
- 선별장 컨베이어 벨트 위에서 촬영된 영상

jpg, jepg,
png 이미지
데이터
- 재활용 어플리케이션을 통해 수집된 실 생활 다양한 환경에서 촬영된 오브젝트
- 실내용 분류기에서 수집된 오브젝트 촬영

- 23 -
- 인 하우스 형태로 자체 개발 정제 웹페이지를 이용하여 이미지화 된 데이터을 정제 기준에 맞 춰 분류 및 삭제
- 5명의 작업자에게 동일한 이미지를 부여하여 과반수 이상이 채택한 답변을 최종 분류로 선정하 여 정제 데이터 퀄리티를 향상 시킴

◯ 정제 절차 예시

4.3 정제 기준

항목 | 설명

사용불가사진

Ÿ 초점이 맞지 않는 프레임
Ÿ 신체 일부가 나온 프레임
Ÿ 컨베이어 벨트의 작동 중지로 인한 중복 프레임 Ÿ 오브젝트 군집화
Ÿ 조명으로 인한 오브젝트 식별 불가능

분류 기준

초점이 맞지 않은 예시 | 신체 일부가 나온 예시 | 중복 이미지 예시
오브젝트 군집화 예시 | 조명으로 인한 오브젝트 식별 불가능 예시

4.4 정제 도구
◯ 영상 데이터 이미지화 및 넘버링
- Python의 OpenCV를 이용하여 영상 데이터를 2초당 1장의 이미지 데이터화 작업을 진행하여 총 200,000장으로 이미지화를 진행 후 중복된 숫자를 허용하지 않고 리네이밍 진행

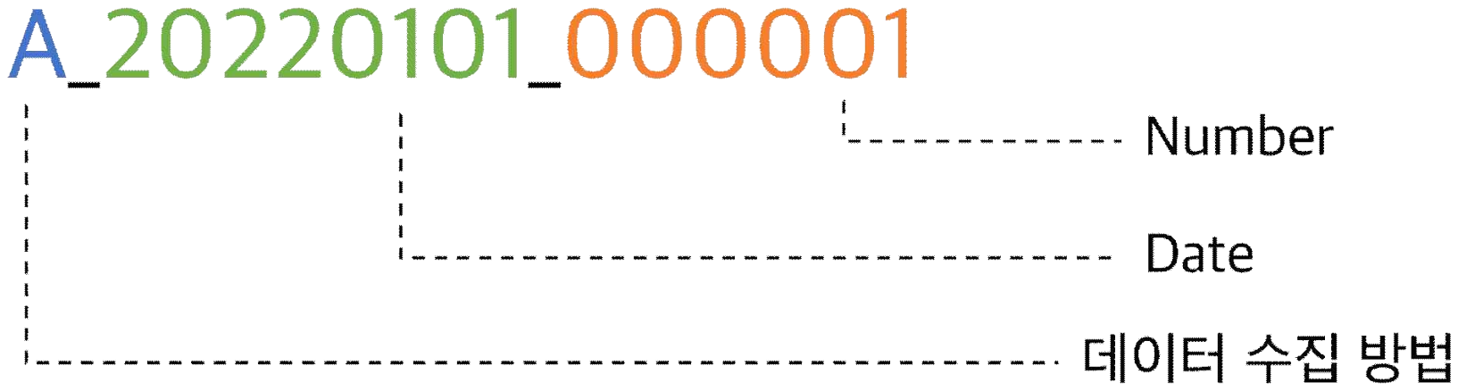
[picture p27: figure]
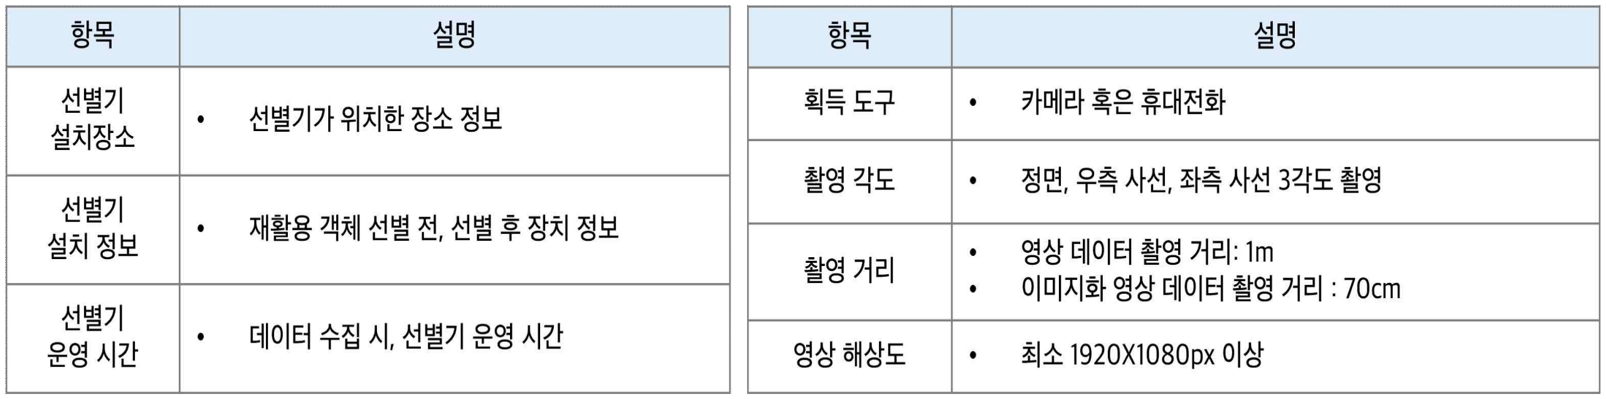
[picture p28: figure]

- 24 -

Ÿ 이미지 넘버링 예시

원시 데이터 | 원천데이터
영상
데이터
수집방법_수집날짜_000000. mp4 | 수집방법_수집날짜_000001.jpg ~ 수집방법_수집날짜_999999.jpg

이미지
데이터
수집방법_수집날짜_000000. jpg | 수집방법_수집날짜_000001.jpg ~ 수집방법_수집날짜_999999.jpg
분류1 (데이터 수집 방법) | _ | 분류 2 (Date) | _ | 분류 3 (Number) | format
A | _ | 20220101 | _ | 000001 | .jpg .jpeg .png

데이터 파일 명명 규칙

정제 기준에 맞지 않는 이미지 데이터는 보류로 분류하고, 정제가 완료된 데이터를 Synology Nas에 저장 후 클라우드에 저장

### 5. 가공(라벨링)

◯ 시스템/프로그래밍을 활용하여 원시 데이터에서 입수한 정보(촬영 Meta data, 재활용 객체 상세 정보 등)를 기계적으로 자동 입력

메타데이터

- 25 -

◯ 높은 데이터 품질을 위해 가공 단계를 분리하여 운영
① 재활용 객체 데이터 중심으로 학습된 AI 모델을 이용하여 다양한 높이와 각도에서 촬영된 제품 이미지 데이터에 특화된 Custom AI 생성
② Custom AI를 활용하여 AI Labeling(자동 라벨링)으로 1차 가공 진행 후, 크라우드 소싱 라벨 링으로 AI Labeling 결과 중 오류사항을 중점적으로 작업
③ 전문 작업자가 2차 검수 진행하며 오류 발견 시 피드백과 함께 반려 진행하여 재작업 진행 ④ 피드백이 반영되어 제출된 데이터를 최종 검수자가 육안으로 검사를 진행하여 데이터 품질 확보

자동라벨링 및 데이터구축(가공/검수) 절차

◯ 라벨링 데이터 대상으로 자체적으로 의미적 검사와 구문적 검사를 수행하여 데이터 품질 확보 ◯ 메타 데이터 입력-가공-검수-검증 일련의 과정(Cycle) 종료 후 이슈 사항 파악하여 반영하며 이 후 Cycle를 반복하여 대규모 데이터 구축 진행

구분 | 주요내용 | 비고
데이터 메타정보 입력 | - 원시데이터에서 입수한 정보를 기계적으로 자동 입력 - 수집 장소, 일시 등의 기타 정보 | 시스템/프로그래밍을 통한 입력
데이터 구축 (AI자동화 및 사람라벨링 작업) | - 1차 가공 (전문가를 통한 정교한 GT 구축) · 최소 6개월 이상 근무자 투입 예정 | AI가공을 위한 전문 인력의 1차 가공 - 2차 가공 – Custom AI 생성 및 AI Labeling
| · 구축된 데이터에 특화된 AI 개발/활용 | 프로젝트 수행 중 지속 개발/ 활용
| - 3차 가공 – 크라우드소싱 · AI Labeling 결과 중 오류사항 작업 | 크라우드소싱 가공
| - 4차 가공(1차 검수) - 전문가 검수 · 전문가의 검수 결과 및 피드백 공유, 최종수정 진행 | 전문가 검수 (가공 유 경험자)
데이터 검증 | - 자체 데이터 검수 수행 · 의미적 검사 : 샘플링 · 구문적 검사 : 전수 | 전문가 검수

1Cycle 중심의 검사 (1차 검사) + 홍보/데이터 검증 (경진대회)

데이터 구축 /
검증 반복
- 기존 Process를 반복하여 대규모 데이터 가공/검증
- 1cycle 이후 이슈 사항 파악 및 반영

1Cycle 결과 기반
컨소시엄 미팅 진행
→ 개선사항 반영

- 26 -

5.2 가공(라벨링) 기준
◯ Bounding Box

① 클래스 및 가공 대상 정의
Ÿ 재활용 분류기를 통해 수집하는 다양한 객체에 대해, 객체 탐지를 위한 대상 및 클래스를 정의 함
NO | 대분류 | 1차 코드 | 2차 내용 | 코드 2차 | 2차 내용 | 3차 코드 | 3차 내용 | 4차 코드 | 4차 내용 | Class
1 | 재활용 | c_1 | 종이 | | | | | | | c_1
2 | | c_2 | 종이팩 | 1 | 우유팩, 주스팩, 두유팩 | | | | | c_2_01
3 | | c_2 | 종이팩 | 2 | 종이컵 | | | | | c_2_02
4 | | c_3 | 캔류 | | | | | | | c_3
5 | | c_4 | 유리 | 1 | 재사용 (소주병 + 맥주병) | 2 | 유리병 만 | | | c_4_01_02
6 | | c_4 | 유리 | 2 | 재활용 | 1 | 갈색 | 2 | 유리병 만 | c_4_02_01_02
7 | | c_4 | 유리 | 2 | 재활용 | 2 | 녹색 | 2 | 유리병 만 | c_4_02_02_02
8 | | c_4 | 유리 | 2 | 재활용 | 3 | 백색 | 2 | 유리병 만 | c_4_02_03_02
9 | | c_4 | 유리 | 3 | 기타 | | | | | c_4_03
10 | | c_5 | 페트 | 2 | 투명 무색 페트만 | | | | | c_5_02
11 | | c_6 | 플라스 틱 | | | | | | | c_6
12 | | c_7 | 비닐 | | | | | | | c_7
13 | | 이물질 | c_1 | 종이 | 1 | 종이 + 이물질 | | | | | c_1_01
14 | | | c_2 | 종이팩 | 2 | 종이컵 | 1 | 종이컵 + 이물질 | | | c_2_02_01
15 | | | c_3 | 캔류 | 1 | 캔 + 이물질 | | | | | c_3_01
16 | | | c_4 | 유리 | 3 | 기타 | 1 | 기타 유리 + 이물질 | | | c_4_03_01
17 | | | c_5 | 페트 | 1 | 투명 무색 페트 + 부속품 | 1 | 이물질 | | | c_5_01_01
18 | | | c_5 | 페트 | 2 | 투명 무색 페트만 | 1 | 이물질 | | | c_5_02_01
19 | | | c_6 | 플라스 틱 | 1 | 플라스틱 + 이물질 | | | | | c_6_01
20 | | | c_7 | 비닐 | 1 | 비닐 + 이물질 | | | | | c_7_01
21 | | 복합재 질 | c_4 | 유리 | 1 | 재사용 (소주병 + 맥주병) | 1 | 유리 + 부속품 | | | c_4_01_01
22 | | | c_4 | 유리 | 2 | 재활용 | 1 | 갈색 | 1 | 유리 + 부속품 | c_4_02_01_01
23 | | | c_4 | 유리 | 2 | 재활용 | 2 | 녹색 | 1 | 유리 + 부속품 | c_4_02_02_01
24 | | | c_4 | 유리 | 2 | 재활용 | 3 | 백색 | 1 | 유리 + 부속품 | c_4_02_03_01
25 | | | c_5 | 페트 | 1 | 투명 무색 페트 + 부속품 | | | | | c_5_01
26 | 추가 | | c_8 | 스티로 폼 | 1 | 흰색 | | | | | c_8_01
27 | | | c_8 | 스티로 폼 | 2 | 컬러 | | | | | c_8_02
28 | | | c_8 | 스티로 폼 | 1 | 흰색 | 1 | 이물질 | | | c_8_01_01
29 | | | c_9 | 건전지 | | | | | | | c_9

일반
쓰레
기

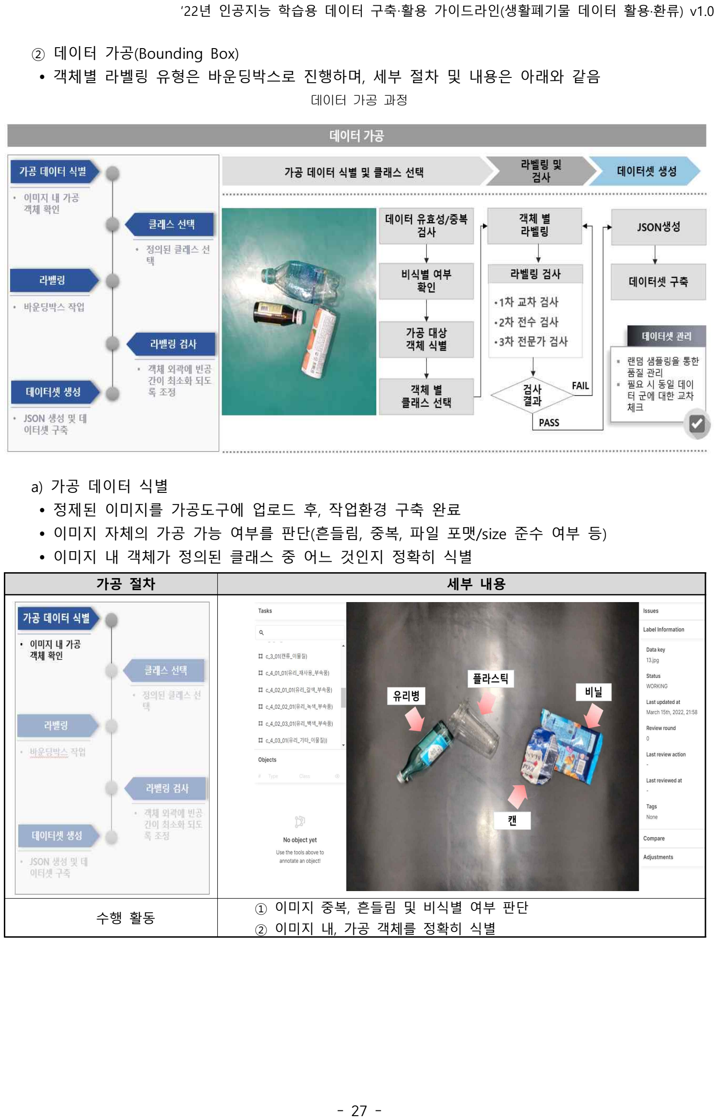
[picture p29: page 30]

- 27 -

② 데이터 가공(Bounding Box)
Ÿ 객체별 라벨링 유형은 바운딩박스로 진행하며, 세부 절차 및 내용은 아래와 같음
a) 가공 데이터 식별
Ÿ 정제된 이미지를 가공도구에 업로드 후, 작업환경 구축 완료
Ÿ 이미지 자체의 가공 가능 여부를 판단(흔들림, 중복, 파일 포맷/size 준수 여부 등) Ÿ 이미지 내 객체가 정의된 클래스 중 어느 것인지 정확히 식별
가공 절차 | 세부 내용
수행 활동 | ① 이미지 중복, 흔들림 및 비식별 여부 판단 ② 이미지 내, 가공 객체를 정확히 식별

데이터 가공 과정

- 28 -
b) 클래스 선택
Ÿ 가공하고자 하는 객체의 클래스를 가공 도구 좌측의 클래스 리스트에서 찾아 선택
가공 절차 | 세부 내용
수행 활동 | ① 가공도구에서 객체에 해당하는 클래스를 검색하여 선택 ② 클래스가 없는 경우, 관리자에서 추가 요청하여 작업환경 개선
c) 객체 라벨링
Ÿ 클래스 선택 후, 화면에 표시되는 십자선을 대상 객체 위치로 이동
Ÿ 이미지를 확대 하여, 객체의 좌-우 길이 및 상-하 높이를 파악
Ÿ 객체가 모두 포함될 수 있도록 좌측 상단부터 우측 하단까지 마우스 드래그 하여 바운딩 박스 생성
가공 절차 | 세부 내용
- 십자선 이동 및 객체 크기 판단
- 마우스를 사용하여 객체가 포함되도록 바운딩박스 생성
수행 활동 | ① 객체가 바운딩박스 안에 포함될 수 있도록 라벨링 작업 수행

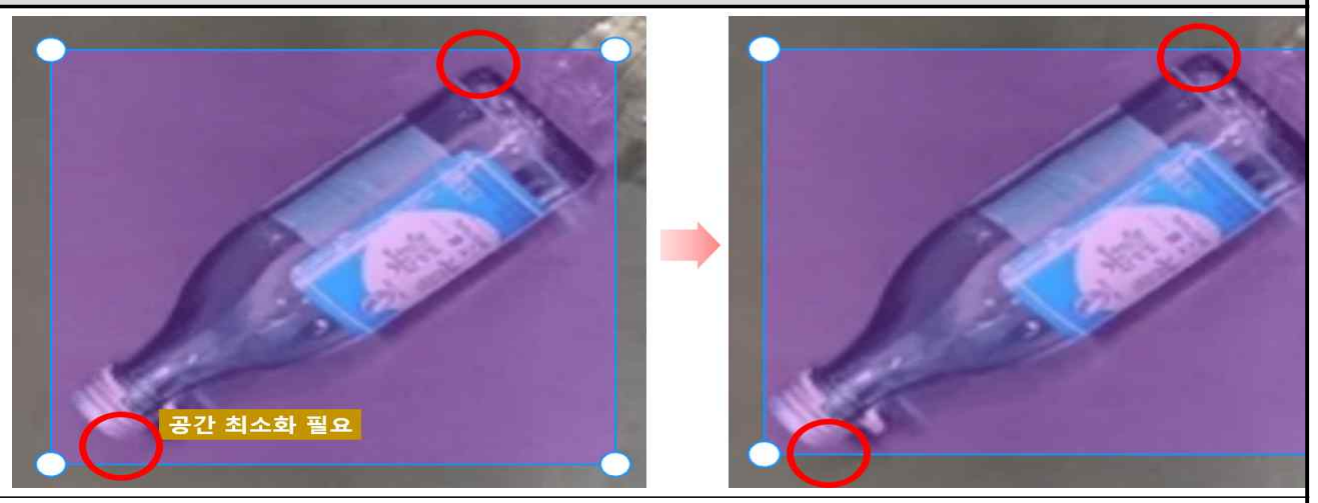
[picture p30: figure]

- 29 -
d) 라벨링 검사
Ÿ 바운딩 박스와 객체간의 간격이 최소화 되도록 확인 후, 필요시 보정
Ÿ 전문 리뷰어의 교차 검사 및 전수검사, 전문가 검사를 통해 라벨링 정확도를 높여 고품질 데이터 셋 구축
가공 절차 | 세부 내용
수행 활동 | ① 바운딩박스의 정확도를 높이기 위해, 바운딩박스의 수평/수직선이 객 체 외곽에 정확하게 위치할 수 있도록 확인 및 보정 작업 수행
e) 데이터셋 생성
Ÿ 가공 완료 후, 가공 도구에서 제공하는 ’JSON Download’버튼 클릭하면 json파일 생성 Ÿ 개별 이미지 및 프로젝트 단위로 사용자 선택에 맞게 생성 가능
Ÿ 가공 도구에서 지원하는 다양한 옵션 기능을 통해, 어노테이션 정보 시각화 기능 제공
가공 절차 | 세부 내용
수행 활동 | ① 가공작업 완료 후, Json파일을 생성함으로서 데이터셋을 생성함

③ 객체 가림 데이터 가공(Bounding Box)
Ÿ 수집/정제된 데이터에서 발생할 수 있는 객체 가림 데이터의 가공 기준
Ÿ 데이터의 가림 현상은 다양한 형태로 발생하므로, 객체의 가림 비율을 판단하고 해당 객체의 외형을 경험적으로 유추하여 바운딩박스 가공 진행
Ÿ 객체의 가림 정도가 약 80~90% 높을 경우, 해당 객체가 어떠한 형태인지 판단하기 모호한 경우에는 가공 제외로 판단함
Ÿ 가림이 심한 객체가 다수 포함된 이미지의 경우는, 가공 대상에서 제외함

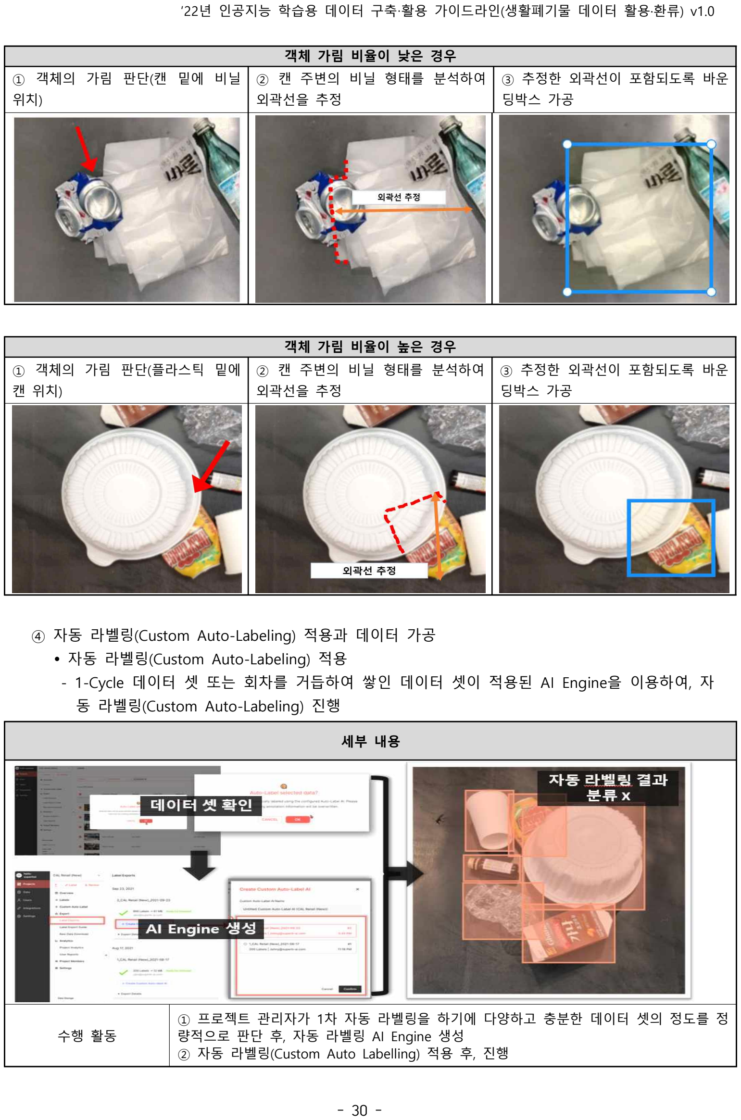
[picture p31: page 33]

- 30 -

객체 가림 비율이 낮은 경우
① 객체의 가림 판단(캔 밑에 비닐
위치)

② 캔 주변의 비닐 형태를 분석하여
외곽선을 추정

③ 추정한 외곽선이 포함되도록 바운
딩박스 가공

객체 가림 비율이 높은 경우
① 객체의 가림 판단(플라스틱 밑에
캔 위치)

② 캔 주변의 비닐 형태를 분석하여
외곽선을 추정

③ 추정한 외곽선이 포함되도록 바운
딩박스 가공

④ 자동 라벨링(Custom Auto-Labeling) 적용과 데이터 가공
Ÿ 자동 라벨링(Custom Auto-Labeling) 적용
- 1-Cycle 데이터 셋 또는 회차를 거듭하여 쌓인 데이터 셋이 적용된 AI Engine을 이용하여, 자 동 라벨링(Custom Auto-Labeling) 진행

세부 내용

수행 활동

① 프로젝트 관리자가 1차 자동 라벨링을 하기에 다양하고 충분한 데이터 셋의 정도를 정 량적으로 판단 후, 자동 라벨링 AI Engine 생성
② 자동 라벨링(Custom Auto Labelling) 적용 후, 진행

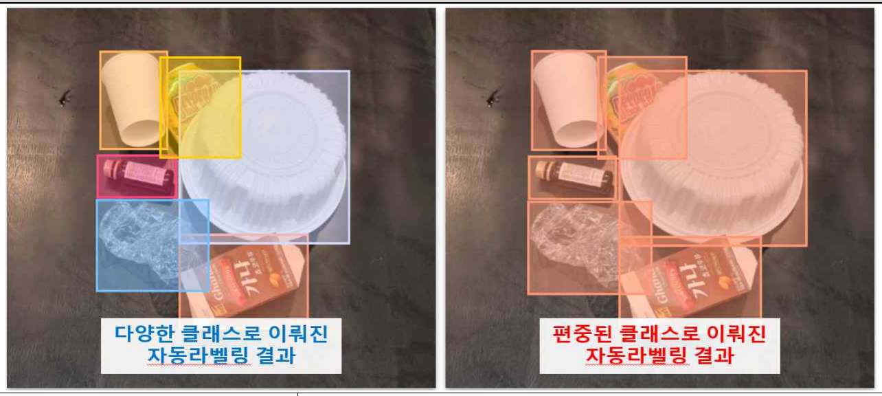
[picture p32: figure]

- 31 -

Ÿ 자동 라벨링(Custom Auto Labelling) 결과물 수정 검수
- 다양한 클래스로 이뤄진 데이터 셋으로 세팅된 AI Engine은 고성능이라고 볼 수 있고 자동 라벨링(Custom Auto Labelling)의 결과도 수작업(Manual Labelling)의 결과와 비교할 시, 기 준에 부합하는 라벨링 데이터 값(Ground Truth)을 얻을 수 있음
- 다양하지 못하거나 어느 하나의 클래스에 편중된 데이터 셋으로 세팅된 AI Engine은 해당 클 래스에 대해서만 고성능이며, 다른 클래스에 대해서는 상대적으로 낮음
- 성능 향상을 위해 자동 라벨링(Custom Auto Labelling)의 결과물을 최대한 수작업(Manual Labelling)으로 수정 검수 진행
- 수작업(Manual Labelling)으로 자동 라벨링(Custom Auto Labelling) 결과값을 기준에 부합하는 라벨링 데이터(Ground Truth)에 가깝게 작업

세부 내용

수행 활동

① 프로젝트 관리자는 기존 데이터 셋으로 만들어진 AI Engine의 자동라벨링 성능을 확인하고 수작업(Manual Labelling)으로 기준에 부합하는 라벨링 데이 터 값(Ground Truth)으로 작업

Ÿ ①+② 과정의 반복 수행(Iteration)을 통해 자동라벨링을 위한 AI Engine 성능을 점진적으로 고도화

- 자동라벨링을 통해 라벨링(Bounding Box)과 분류(Classification) 작업에 투입되는 수작업
| (Manual Labelling)을 최소화 하고, 라벨링 결과에 대한 검사와 보정작업에 집중함으로서 고품 질 데이터셋 구축

- 32 -

□ 클래스별 데이터 예시

데이터 예시 및 클래스 분류

Class Code | 분류 | Class Code | 분류 | Class Code | 분류
c_1 | 종이 | c_2_01 | 종이팩, 우유팩, 주스팩, 두유팩 | c_2_02 | 종이팩 종이컵
Class Code | 분류 | Class Code | 분류 | Class Code | 분류
c_3 | 캔류 | c_4_01_02 | 유리 재사용 (소주병 + 맥주병)/유리병만 | c_4_02_01_02 | 유리 재활용 갈색
Class Code | 분류 | Class Code | 분류 | Class Code | 분류
c_4_02_02_02 | 재활용/녹색 유리 | c_4_02_03_02 | 재활용/백색 유리 | c_4_03 | 유리 기타
Class Code | 분류 | Class Code | 분류 | Class Code | 분류
c_5_02 | 페트 투명 무색 페트만 | c_6 | 플라스틱 | c_7 | 비닐
Class Code | 분류 | Class Code | 분류 | Class Code | 분류
c_1_01 | 종이 + 이물질 종이 | c_2_02_01 | 종이컵 + 이물질 종이팩/종이컵 | c_3_01 | 캔류 캔 + 이물질

- 33 -
Class Code | 분류 | Class Code | 분류 | Class Code | 분류
c_4_01_01 | 유리 재사용 (소주병 + 맥주병) 유리 + 부속품 | c_4_02_01_01 | 유리 재활용 갈색 | c_4_02_02_01 | 유리 재활용 녹색
Class Code | 분류 | Class Code | 분류 | Class Code | 분류
c_4_02_03_01 | 유리 재활용 백색 | c_4_03_01 | 유리/기타 기타 유리 + 이물질 | c_5_01 | 페트 투명 무색 페트 + 부속품
Class Code | 분류 | Class Code | 분류 | Class Code | 분류
c_5_01_01 | 페트 투명 무색 페트 + 부속품/이물질 | c_5_02_01 | 페트 투명 무색 페트만/이물질 | c_6_01 | 플라스틱 플라스틱 + 이물질
Class Code | 분류 | Class Code | 분류 | Class Code | 분류
c_7_01 | 비닐 + 이물질 비닐 | c_8_01 | 스티로폼 흰색 | c_8_02 | 스티로폼 컬러
Class Code | 분류 | Class Code | 분류 | Class Code | 분류
c_8_01_01 | 스티로폼/흰색 이물질 | c_9 | 건전지

- 34 -

라벨링데이터 포맷

◯ 어노테이션 구조(JSON)

구분 | 속성명 | 타입 | 필수 여부 | 설명
1 | objects | array | Y
| 1-1 | objects.id | string | N | 라벨링 시 부여되는 이미지당 id
| 1-2 | objects.class_id | string | N | 라벨링 시 부여되는 어노테이션당 id
| 1-3 | objects.tracking_id | number | N | 이미지 번호
| 1-4 | objects.class_name | string | Y | 클래스명
| 1-5 | objects.annotation_type | string | Y | 어노테이션 타입
| 1-6 | objects.annotation | object | Y
| 1-6-1 | annotation[].coord | object | Y
| 1-6-1-1 | annotation[].coord[].x | number | Y | box의 좌측상단x좌표
| 1-6-1-2 | annotation[].coord[].y | number | Y | box의 좌측상단 y 좌표
| 1-6-1-3 | annotation[].coord[].width | number | Y | box의 너비
| 1-6-1-4 | annotation[].coord[].height | number | Y | box의 높이
1-6-2 | | annotation[].meta | object | N
| 1-6-2-1 | annotation[].meta[].z_index | number | N | box의 생긴 순서
| 1-6-2-2 | annotation[].meta[].visible | boolean | N | box의 visible 여부
| 1-6-2-3 | annotation[].meta[].alpha | number | N | 특정 번호
| 1-6-2-4 | annotation[].meta[].color | string | N | box의 색상
1-7 | objects.properties | array | N | 객체의 속성
2 | categories | object | N
| 2-1 | categories.properties | array | N | box의 속성
3 | | Image | string | Y | 이미지 이름
4 | | Info | object | Y
| 4-1 | Info.PLACE | string | Y | 실내/실외
| 4-2 | Info.GPS | string | Y | GPS 좌표
| 4-3 | Info.ADDRESS | string | Y | 주소
| 4-4 | Info.METHOD | string | Y | 촬영방법
| 4-5 | Info.DATE | string | Y | 촬영날짜 및 시간
| 4-6 | Info.DAY/NIGHT | string | Y | 주간/야간
| 4-7 | Info.DEVICE | string | Y | 촬영장비
| 4-8 | Info.BRAND | string | Y | 촬영브랜드
| 4-9 | Info.RESOLUTION | string | Y | 이미지 해상도
| 4-10 | Info.COLOR | number | Y | 이미지 컬러값
| 4-11 | Info.ROTATE | number | Y | 이미지 회전값
| 4-12 | Info.EXPOSURE | string | Y | 이미지 노출값
| 4-13 | Info.ISO | number | Y | 이미지 ISO값

- 35 -

◯ 어노테이션(Bounding Box) 산출물(json) 예시

객체 라벨링 | json 예시

5.3 가공(라벨링) 조직

◯ 데이터 관리 조직 구성

관리조직 | 주요내용
데이터 관리 조직 | 원시 데이터 관리자, 원천 데이터 관리자, 가공 데이터 관리자, 프로세스 관리자로 구성
원시 데이터 관리자 | 획득한 원시 데이터의 백업을 관리하고, 수집된 원시데이터를 하드디스크 또는 NAS, 클 라우드 서비스 등에 관리
원천 데이터 관리자 | 획득한 원천 데이터의 백업을 관리하고, 원시데이터 관리자를 통해 전달받은 데이터를 하드디스크 또는 NAS, 클라우드 서비스 등에 관리
가공 데이터 관리자 | 획득한 가공 데이터의 백업을 관리하고, 전달받은 원천 데이터를 통해 구축된 가공 데 이터에 대한 데이터를 관리하며 프로세스 관리자에게 보고
프로세스 관리자 | 원시, 원천, 라벨링 데이터 관리자로부터 데이터 현황 및 문제를 전달받아 내용의 일치 성과 정확성을 검토 후 데이터 구축 현황 및 시스템 점검을 실시

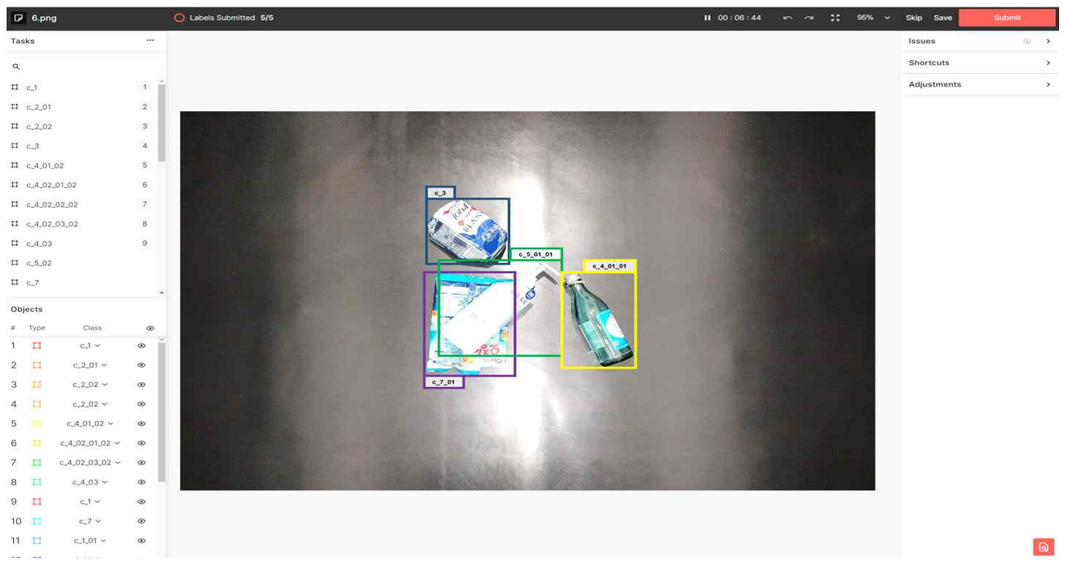
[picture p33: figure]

- 36 -

5.4 가공(라벨링) 도구

No | 특징 | 주요내용
1 | Suite APP | 시간과 장소에 제약없이 온라인 접속을 통해 접근 및 데이터 구축 작업 가능
2 | Labeling Type | 다양한 데이터 가공 형태 지원 -바운딩박스, 폴리곤, 키포인트, LiDAR, DiCOM등
3 | Custom Auto Labeling | 커스텀 오토라벨링을거친 데이터를 추가 검수하여 데이터의 품질을 개선
4 | Consensus Labeling | 동일한 데이터를 여러 명이 작업하도록 하여, 라벨링된결과의 일치도(Consistency)를 기반 으로 데이터셋의 품질을 평가
5 | Server, GPU | 4xAMD EPYC 7413 24-Core Processor (2.65GHz-96 Core) 2xGPU - A6000 (48GB) 2xCPU-Xeon-5218R@2,01GHZ 4xGPU-Titan-RTX-24GB 2xCPU-Xeon-5120@2,20GHZ 4xGPU-Titan-RTX-24GB
6 | SOC2 | SOC 2 Type II 인증 획득 SOC2TypeII는 Systems and Organization Controls 프로토콜 내에서 가장 포괄적인 인증 이며, 시스템이 고객의 중요한 데이터를 안전하게 유지하도록 설계되었음을 증명하는 인 증체계
7 | ESET | 시장에서 가장 앞선 악성코드 방어 솔루션 적용
8 | Vanta | 시스템 운영/관리자 정보보안 관련 정책 및 교육 이수

◯ 데이터 가공 도구
슈퍼브에이아이가 자체 개발한 플랫폼인 스위트(Suite)는 AI기반의 가공/검수, 작업자(라벨러/검 수자) 기반의 가공/검수 시스템이 구성되어 있음. 슈퍼브에이아이는 스위트를 활용하여 다양한 도메인의 데이터 용역을 수행하고 있으며 2020년/2021년 TTA의 데이터 품질 검사(의미적 정확 성)를 담당하며, 플랫폼의 품질 및 사용성 등 그 우수성을 인정받음

<스위트(Suite) WorkApp 화면 – Bounding Box>

- 37 -

◯ 가공 도구 특징
Ÿ 대규모 데이터 구축 시, 효율적인 운영을 위한 데이터 관리 플랫폼과 데이터 서비스 제공

가공 도구 Suite 솔루션 특징

◯ 데이터 라벨링 모니터링
- 데이터 구축도구인 스위트(Suite)에서 데이터 라벨링 현황 파악을 위해 시각화된 대시보드를 제 공함으로써, 전체 공정의 모니터링을 빠르게 진행

① 데이터셋 파악을 위한 실시간 통계 및 시각화 정보 제공

Suite 모니터링 기능

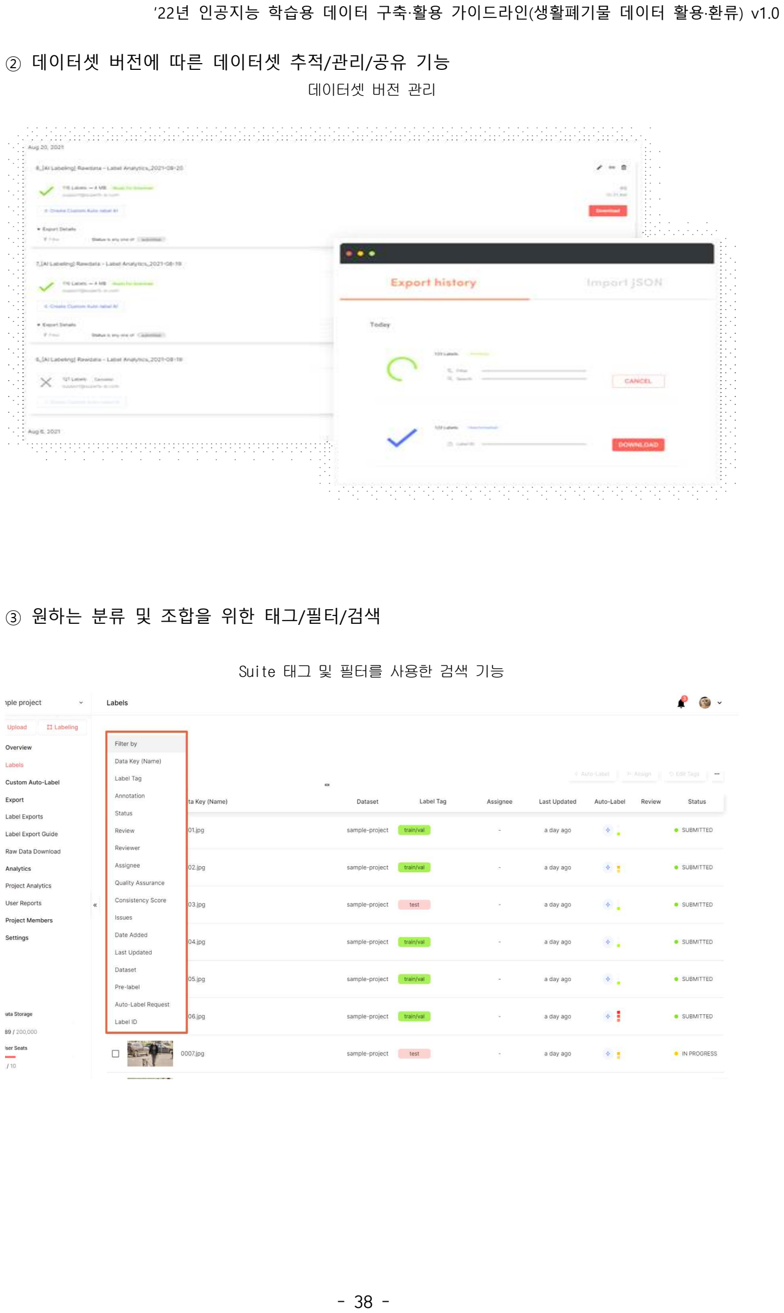
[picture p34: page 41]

- 38 -

② 데이터셋 버전에 따른 데이터셋 추적/관리/공유 기능

데이터셋 버전 관리

③ 원하는 분류 및 조합을 위한 태그/필터/검색

Suite 태그 및 필터를 사용한 검색 기능

- 39 -

프로젝트 내 다양한 이해관계자 별 권한 분리/실시간 협업 및 소통

Worker (라벨링작업자)
Ÿ 라벨링툴을 활용해 할당된 데이터 라벨링작업 진행 Ÿ 작업 결과물을 바탕으로 매니저와 실시간 소통 Ÿ 할당된 데이터에만 접근 가능

Manager (프로젝트 관리자)
Ÿ 작업자 초대 및 작업량 할당
Ÿ 작업 결과물 리뷰 및 승인
Ÿ 할당된 프로젝트에만 접근 가능

Owner/Admin
Ÿ 데이터/사용자/프로젝트를 관리 권한

기존 개발 환경과 연동을 통한 데이터 파이프라인 구축 지원

Developer Tools

Ÿ 기존에 개발한 머신 러닝 모델의 결과값업로드 지원 (Model-Assisted Labeling)
Ÿ SDK/CLI 를 통해 여러 데이터 작업을 간편하게 수행

Integration

Ÿ 고객사 퍼블릭 클라우드와의 연동을 통한 데이터 보안 강화 (Read only 형태로만 연동)
Ÿ 주요 머신러닝개발환경, 서비스, 데이터 스토리지와 연동 가능

최신 AI 기술을 접목하여 데이터 구축/관리/분석 관련 자동화 지원

Auto-Label & Uncertainty Estimation*

Ÿ 다양한 object 에 대한 자동 라벨링및 자동 검수
Ÿ 고객 데이터에 학습된 맞춤 AI 생성 (Custom Auto-Label)
Ÿ 수동 라벨링대비 10배* 생산성 향상 가능 레퍼런스 보유
* 자체 연구 결과로 실제 고객 사례 중에는 10배 이상의 생산성 효과를 얻은 경우도 있음
Ÿ 관련 미 특허 11종 등록
Ÿ 최신 AI 기법을 활용한 여러 자동화 기능 지속 출시 예정 Ÿ 사람 라벨링오류 자동 탐지 (Mis-label detection)
Ÿ 데이터 속성 자동 추출/분류/검색 (Feature extraction)

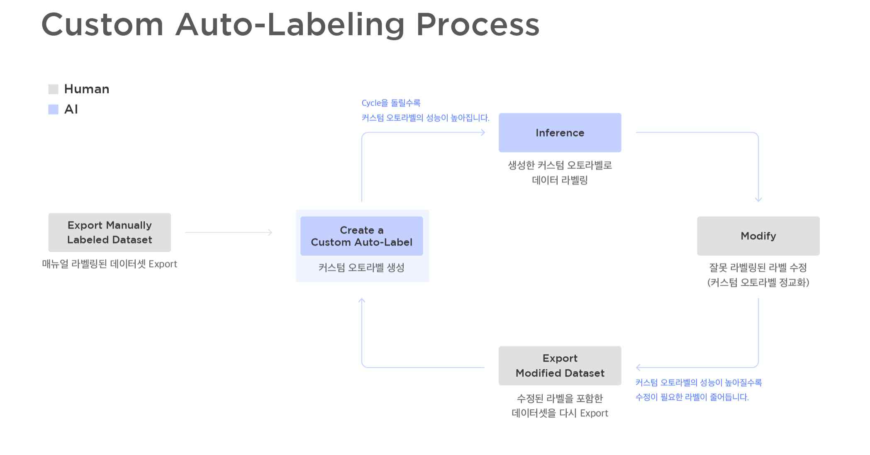
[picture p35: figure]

- 40 -
- 자동 라벨링(Custom Auto-Labeling) 특장점
- 자동라벨링은 다음의 2가지 기능을 함께 지원하여 사용자의 라벨링 작업과 검사를 효율적으로 지원함
- 라벨링 작업 난이도 측정 및 분류 : 가공 대상 객체별 작업 난이도는 Auto-Label컬럼에 표시됨 (*빨간색-어려움, 노란색-보통, 초록색-쉬움) 사용자는 난이도별로 라벨을 쉽게 정렬하고 필터링 할 수 있음
- 불확실성이 높은 어노테이션 강조 : 자동라벨링으로 작업한 어노테이션 중 불확실성(uncertainty) 이 높은 것은 AI가 자동 판단하여 리뷰 모드에서 노란색으로 강조하여 표시합니다. 사용자는 AI 가 표시한 이 어노테이션을 우선적으로 검수할 수 있음
- 1-Cycle을 활용한 자동 라벨링(Custom Auto-Labeling) 적용 방안

가공 도구 suite의 자동 라벨링 절차 개념도

- Export Manually Labeled : 자동라벨링 AI Engine을 생성하기 위해서는 라벨링이 완료된 데이터 셋이 최소 1000장 이상 필요하므로, 초기 1-Cycle 구축 공정을 통해 생성되는 데이터셋을 사용 함
- Create a Custom Auto-Label : 1-Cycle를 통해 생성한 데이터셋을 사용하여 AI Engine을 생성 함

자동라벨링을 위한 AI Engine생성

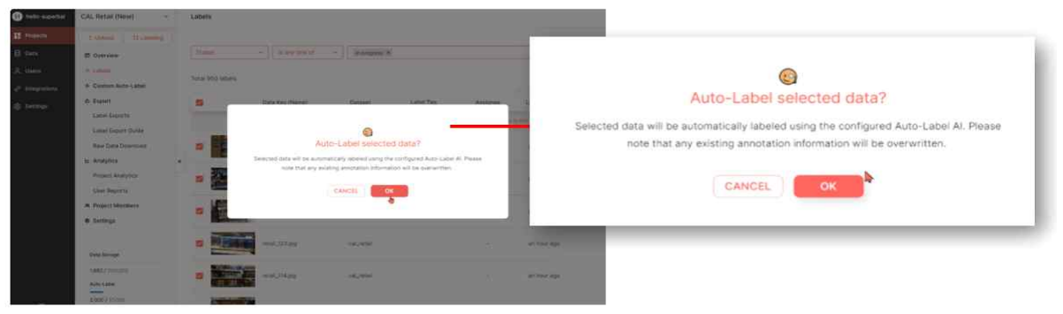
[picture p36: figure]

- 41 -
- Inference : 생성된 AI Engine을 사용하기 위한 세부 설정을 수립하고, 가공 대상 이미지를 선택 하여 자동라벨링(Custom Auto-Labeling)을 적용함
- Modify : 자동라벨링이 적용된 결과를 리뷰하여, 필요한 부분은 수정하여 데이터셋을 보정함
- Export Modified Dataset – Repeat(Create Again a Custom Auto-Label) : 보정된 데이터셋을 Export하여, 라벨링이 완료된 데이터를 더 많이 준비하고 자동라벨링 AI를 재학습함으로써, AI Engine을 더욱 정교하게 생성함
- 자동라벨링(Custom Auto-Labeling) 생성 Iteration을 통한 성능 향상
- 라벨링이 완료된 데이터셋의 양이 많고, 라벨링의 정확도가 높을수록 자동라벨링을 위한 AI Engine 성능이 향상됨
- 일정량의 데이터셋이 구축될 때마다, 단계적으로 새로운 자동라벨링 AI Engine을 재학습(업그레 이드)함으로써 지속적으로 성능을 향상시킴으로써, 객체 검출 정확도를 향상시킬 수 있음

자동 라벨링 AI Engine 성능 향상

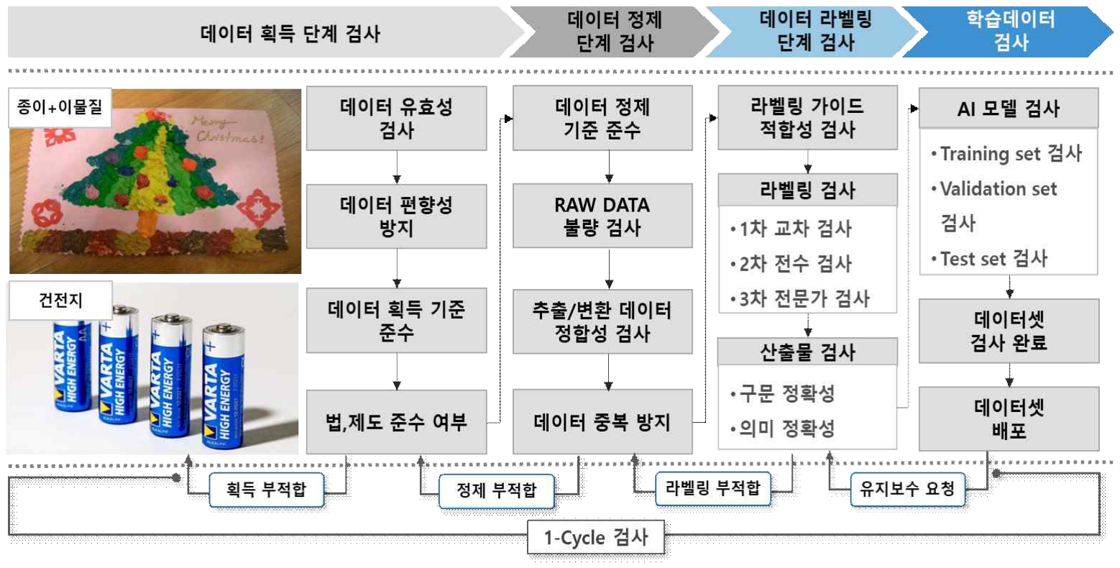
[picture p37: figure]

- 42 -

### 6. 검사

6.1 검사 절차

6.2 검사 기준
◯ 각 단계별 검사 정의
구분 | 주요내용
획득 | 재활용 데이터 수집 및 제작 방안, 요구사항에 적합한 데이터 형태, 법·제도 준수, 사실적인 획득 환경 구성, 데이터 동기화, 편향성 방지
정제 | 데이터 정제 기준 준수, 원천데이터 중복성 및 오류방지, 데이터 정제 작업 매뉴얼, 정제 도구, 정제 작업 방식, 비식별화 대상 및 범위
가공(라벨링) | 라벨링 가이드, 라벨링 유형, 데이터 속성, 라벨링 오류 기준 충족 여부, 비식별화 대상 및 범위
학습데이터 | ① 데이터셋 적합성 여부(Training Set, Validation Set, Test Set) ② 공개 데이터 적합성 여부
검사 절차 | 검사 항목 | 검사 요구사항
데이터 획득단 계 | 데이터 유효성 검사 | 데이터 수집 장비 특성 및 정의된 요구사항을 준수해야 함
| 데이터 편향성 방지 | 데이터 획득 시, 각 클래스별 설계에 따라 수집 분포에 맞 고, 특정 클래스로 편향되지 않도록 고려하여 획득
| 데이터 획득 기준 준수 | 수집 대상 데이터의 세부 분류 체계, 데이터 특성 고려, 각 이해관계자와의 협의 사항 반영
| 법·제도 준수 | 원시 데이터 획득 시 개인정보와 관련된 법·제도적 규정 등 을 반드시 준수하여야 함

- 43 -

◯ 품질 지표

데이터 정제단 계 | 데이터 정제 기준 준수 | ① 데이터 사용 목적에 적합한 정제 기준 준수 여부 ② 재활용 객체에 개인정보 관련 부위 제거 여부
| Raw data 불량검사 | 데이터 획득 단계에서 수집된 원시 데이터 자체의 파손/불량 여 부
| 추출/변환 데이터 정합성 검사 | 라벨링 데이터로 부적합한 이미지 ① 초점이 맞지 않은 사진 ② 신체 일부가 나온 사진 (손, 발) ③ 형체를 인식하기 힘들 정도의 밝기 ④ 오브젝트가 앵글을 벗어난 사진 ⑤ 메뉴얼 기재 내용 이외의 이미지
| 데이터 중복 방지 | 대규모 데이터셋 수집에서 발생하는 데이터 중복 여부
데이터 라벨링 단계 | 라벨링 가이드 적합성 검사 | ① 데이터 라벨링, 규칙 사양 문서의 적합성 여부 ② 라벨링 가이드의 사용성, 적합성 여부

라벨링 검사

검사 단계 | 내용
1차 교차 검사 | 라벨링 기준 준수
2차 전수 검사 | 라벨링 품질 정확성
3차 전문가 검사 | 데이터셋 정확성
산출물 검사 | ① JSON 구조 정의를 준수하는지 여부 검사 ② 분류 오류, 영역 오류, 누락된 객체, 불필요한 객체 검사
학습데 이터 단계 | AI모델 검사 | ① 학습데이터 분류에 따른 데이터셋 분류 정확성 ② 모델 학습에 부적합 데이터 포함 여부
| 데이터셋 검사 완료 | 요구사항에 적합한 데이터셋 구축 여부
| 데이터셋 배포 | 공개 데이터로서의 적합성 여부
품질특성 | 항목명 | 측정 지표 | 정량 목표
구문적 정확성 | 구조 정확성 | 정확도 | 99.5% 이상
| 형식 정확성 | 정확도 | 99.5% 이상
의미적 정확성 | 객체 바운딩 박스 정확성 | F1-점수 | 90% 이상
유효성 | 재활용품 분류 성능 | mAP | 90% 이상
| 일반 쓰레기 분류 성능 | mAP | 85% 이상

품질관리 총괄책임자; 품질관리 실무책임자; 품질자문 위원회; 품질관리 실무협의회; 구축공정 품질관리; 구축데이터 품질관리; AI학습모델 품질관리; 박수현,김민경; 전승혁, 최태훈; 정희철

- 44 -

6.3 검사 조직

조직 구분 | 역할과 책임
품질관리 총괄책임자 | Ÿ 인공지능 학습용 데이터의 품질관리 총괄
품질관리 실무책임자 | Ÿ 인공지능 학습용 데이터의 품질관리 실무 총괄
품질관리 실무협의회 | Ÿ 인공지능 학습용 데이터의 품질관리 주요 계획, 품질 현안 등의 협의
품질자문 위원회 | Ÿ 필요 시, 내부 품질관리 과정 및 방법에 대한 3자 검증을 수행
| (전문가 집단으로 구성된 외부 품질자문위원회를 운영)

프로세스 품질관리
담당 | Ÿ 구축 프로세스의 준비성, 완전성, 유용성에 대한 품질관리 담당
데이터 품질관리 담당 | Ÿ 인공지능 학습용 데이터 적합성 및 정확성에 대한 품질관리 담당

학습모델 품질관리
담당 | Ÿ 인공지능 학습용 데이터를 활용한 학습모델에 대한 품질관리 담당

품질관리 조직
품질관리 조직도

- 45 -
품질검사영역 | 구문 정확성 검사 | 의미 정확성 검사 | 학습모델 유효성 검사
도구명 | Json Buddy Validator | Superb AI Suite | 오픈소스 기반 자체개발

설명

1. 모든 데이터셋에 관하여 전수
검사
2. Json의 포맷과 Value값들의
Type 확인
3. 각 Class의 표기 확인

Computer Vision 분야에서 정의
하고 있는 대표적인 품질 측정 지
표 활용 - Classification Error - Low Recall - Low Precision
- Low IOU
1. 검증/테스트 데이터셋을 학습
된 모델로 추론. 2. 학습에 사용된 품질지표로 측

정. 3. 학습 결과와 검사 결과를 서

로 비교하여 유효성 확인

도구유형 | 상용SW | SaaS | 오픈소스 기반 자체개발
주요기능 | 라벨링 데이터 확인(Json), Format, Type, Label, State | - 참값 오류 육안 검사 - 데이터 종류별에 해당하는 어 노테이션과 참값 간의 중첩율을 계산하여 정확도 확인 - 데이터 종류별로 생성된 어노 테이션 중 정답 어노테이션 비율 을 계산하여 정밀도 확인 - 데이터 종류별로 가능한 모든 어노테이션 중 정답 어노테이션 비율을 계산하여 재현율 확인
사용환경 | OS: Window,Mac SW : GUI | Web 기반 소프트웨어 (Chrome 최적화 솔루션)

검증/테스트 셋에 대한 인식 정
확도에 대한 결과를 수치적으로
확인

OS: 리눅스 (우분투)
프레임워크: PyTorch

6.4 검사 도구
품질관리 도구

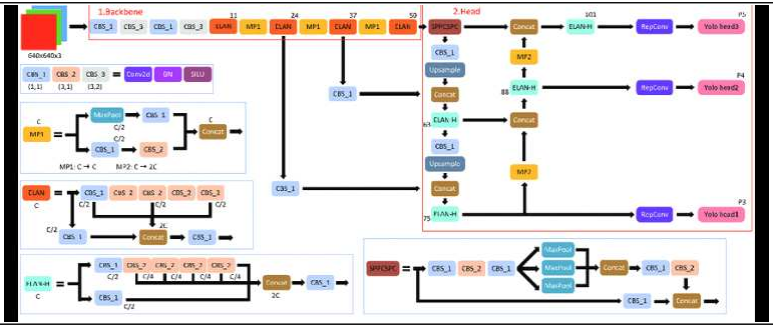
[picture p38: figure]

- 46 -

### 7. 학습 모델

7.1 학습 모델 후보
◯ 객체 탐지(Object Detection)
[ 학습모델 후보군 ]

7.2 학습 모델 개발

[학습 모델 : Yolov7]

구분 | 내 용 | 최종선정
Yolov5 | 후보 선정사유 | Ÿ one-stage detector 대표 모델 중 하나인 YOLO 모델에 여러 딥러닝 기법을 적용하여 기존보다 성능 향상된 모델 Ÿ two-stage detetor와 달리 별도로 RoI를 추출하는 모듈 을 가지지 않아 추론 속도면에서 이점을 가짐
DetectoR S | 후보 선정사유 | Ÿ 최근에 제안된 CNN 기반의 one-stage dector로 recursive FPN 구조를 가지는 것이 특징이 있음. Ÿ 추가로 SAC(Switchable Atrous Convolution)를 통해 다양 한 receptive field를 가지게 하여 모델의 성능을 높임.
Yolov7 | 후보 선정사유 | Ÿ 매개변수와 계산을 효과적으로 활용할 수 있는 실시간 객체 검출기를 위한 방법을 제안한 알고리즘 Ÿ E-ELAN(Extended efficient layer aggregation networks) 와 복합 스케일링(Compound scaling)을 활용하여 그레디 언트 경로를 효율적으로 제어 하고 네트워크를 효과적으 로 학습이 가능하게 함 | O

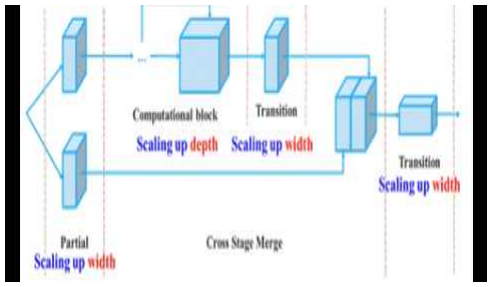
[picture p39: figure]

- 47 -
[E-ELAN] | [Compound scaling]

Ÿ 재활용품 인식 모델 개발 – 객체 탐지(Object Detection) - 재활용품 9가지를 학습하여, 이를 기반으로 재활용품을 탐지

Ÿ 일반쓰레기 인식 모델 개발 – 객체 탐지(Object Detection) - 이물질 및 다중 포장재를 포함한 일반쓰레기를 탐지

- 48 -

## 제3장 데이터 활용

### 1. 데이터 활용

### 2. 응용 서비스 및 개발

2.1 인공지능 데이터 활용 모델 개발 요약표

2.2 인공지능 학습용 데이터 활용모델 개발 방안

1) 딥러닝 기술을 활용한 재활용품 인식 알고리즘 개발

◯ 선행연구 조사
- 비정형 쓰레기 이미지에 대해 분류(classification)을 수행하는 모델 개발 연구가 있었음 (White, Gary, et al. "WasteNet: Waste Classification at the Edge for Smㅁart Bins." arXiv preprint arXiv:2006.05873 (2020).) - 해당 연구는 DenseNet 기반으로 모델을 개발하였고, 0.97의 F1-score를 달성하였으나, 분류 작

업을 수행하기 떄문에 학습 이미지 하나당 객체가 하나만 존재하여 다중 객체 탐지 및 위치 검출이 불가능함

데이터 명 | 생활폐기물 AI 데이터 활용-환류
학습 모델 | 재활용품 탐지 모델 / 일반쓰레기 탐지 모델
모델 | Yolov7
성능 지표 | 재활용품 탐지 모델 mAP@0.5 0.94 / 일반쓰레기 탐지 모델 mAP@0.5 0.93
개발 내용 | 구축되는 학습데이터를 활용 쓰레기의 상태에 따라 재활용품 / 일반쓰레기를 Object Detect이 가능한 Yolov7기반의 모델 개발
응용서비스 (예시 및 유의사항) | 재활용 선별장에서 많은 인력을 이용하여 재활용품 탐지 모델 및 일반쓰레기 탐지 모델을 활용하여 오브젝트 상태에 따라 1차적으로 재활용품으로 분류하고 2차적으로 일반쓰레기를 분류하여 인력부족난을 해결하고 자동화를 통화 선별능력 향상가능
데이터명 | AI 모델 | 모델 성능 지표 | 응용서비스(예시)
재활용품 데이터 | 선별 AI 모델(Yolov5) | mAP | 어플리케이션 (실내용)재활용품 자동 분류기 (대용량)재활용품 자동 선별기

- 49 -

◯ 연구개발 방안 및 학습모델 선정
- 데이터 라벨이 바운딩 박스(bounding box)로 주어지기 때문에 학습 및 수행에 적합한 Task인 객체 탐지 (Object Detection) 모델을 알고리즘 연구개발 모델로 정함 - 학습, 검증, 테스트 데이터는 8:1:1 비율로 나눠 모델 학습을 진행하고 최종적으로 테스트 데이터에서

총 29가지 클래스에 대해 객체 탐지를 수행하는 모델을 개발하는 것을 목표로 함
- 객체 탐지(Object Detection)을 수행하는 딥러닝 모델은 크게 one-stage와 two-stage로 눌 수 있는데 one-stage 모델은 two-stage에 비해 추론속도가 빠르고 파라미터 수가 적어 임베디드 환경에도 적합하다는 장점이 있음
- 최근 CNN 기반의 one-stage 모델 중에서 좋은 성능을 보이는 YOLOv5와 DetectoRS를 후보군 으로 선정하여 연구 개발할 예정임

학습모델 후보군

2) 응용 서비스 개발 및 사업화

◯ 주관기관 ㈜서르는 재활용 폐기물과 관련하여 R&D 및 사업화를 추진하였으며, 주요 추진내 용은 다음과 같이 요약됨

① 재활용 폐기물 데이터셋 구축 및 분류/인식 AI 알고리즘 개발
② 재활용 폐기물 분류 장치 및 어플리케이션 개발
③ 분류기 제어부 시스템 경량화 및 데이터셋 고도화
구분 | 내 용

Ÿ YOLOv5
- one-stage detector 대표 모델 중 하나인 YOLO 모 델에 여러 딥러닝 기법을 적용하여 기존보다 성능 향상된 모델
- two-stage detetor와 달리 별도로 RoI를 추출하는 모 듈을 가지지 않아 추론 속도면에서 이점이 있음

Ÿ DetectoRS - 최근에 제안된 CNN 기반의 one-stage dector로

recursive FPN 구조를 가짐
- SAC(Switchable Atrous Convolution)를 통해 다양한 receptive field를 가지게 하여 모델의 성능을 높일 수 있음

- 50 -

구현 기술 및 시제품

재활용품 인식 어플리케이션

실내용 분류기

대용량 선별기

2.3 인공지능 모델을 적용한 기술혁신 지원 방안

◯ 소스 공개를 통한 데이터 활용
- 생활폐기물 데이터를 활용하고자 하는 개인부터 기업까지 누구나 사용 가능한 데이터셋을 구축 하여 제공하고자 하며, 적절한 연구 승인을 받은 연구자에게 AI hub를 통해 필요한 데이터 및 알고리즘의 사용이 가능하도록 ㈜서르가 지원함

◯ 생활폐기물 관련 데이터 고도화 지원
- 폐기물 전문가 검수를 통해 제공되는 데이터는 이전에 제공되고 있는 데이터보다 오류율을 감 소시키고, 활용도가 높은 데이터로 관련 기술 개발의 고도화를 지원할 수 있음

◯ 생활폐기물 선별소 인공지능 기술 지원
- 공공 및 사설 폐기물 선별소에서 관련 기술을 활용하여 새로운 기계 장치 및 서비스를 설계하는 경우, 데이터 활 용 방법, 알고리즘 고도화 및 적용 등을 지원함으로서 구축된 데이터 사용의 확대를 추진함

◯ 기술 사업화 추진
- 이번 구축된 데이터는 ㈜서르에서 자체적으로 추진하고 있는 폐기물 선별기 고도화에 활용하고 자 하며, 해외보다 우수한 기계장치를 개발하여 기술의 국산화 및 해외 수출을 추진하고자 함

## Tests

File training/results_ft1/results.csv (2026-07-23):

epoch | time | train/box_loss | train/cls_loss | train/dfl_loss | metrics/precision(B) | metrics/recall(B) | metrics/mAP50(B) | metrics/mAP50-95(B) | val/box_loss | val/cls_loss | val/dfl_loss | lr/pg0 | lr/pg1 | lr/pg2
1 | 44.5568 | 0.3619 | 0.41937 | 0.89923 | 0.98041 | 1 | 0.995 | 0.995 | 0.14061 | 0.09687 | 0.75409 | 0.000157785 | 0.000157785 | 0.000157785
2 | 84.5805 | 0.36797 | 0.40537 | 0.8998 | 0.97843 | 1 | 0.995 | 0.995 | 0.15504 | 0.09597 | 0.75214 | 0.000295566 | 0.000295566 | 0.000295566
3 | 124.814 | 0.37787 | 0.41605 | 0.90399 | 0.98893 | 1 | 0.995 | 0.985 | 0.19718 | 0.13044 | 0.76669 | 0.000412403 | 0.000412403 | 0.000412403
4 | 164.781 | 0.38394 | 0.42474 | 0.90467 | 0.9816 | 1 | 0.995 | 0.995 | 0.1853 | 0.13006 | 0.75972 | 0.000381752 | 0.000381752 | 0.000381752
5 | 205.156 | 0.3806 | 0.41039 | 0.90533 | 0.98922 | 1 | 0.995 | 0.995 | 0.16504 | 0.12963 | 0.75219 | 0.000350336 | 0.000350336 | 0.000350336
6 | 248.151 | 0.25136 | 0.31337 | 0.80106 | 0.98351 | 1 | 0.995 | 0.995 | 0.19245 | 0.14977 | 0.75529 | 0.00031892 | 0.00031892 | 0.00031892
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

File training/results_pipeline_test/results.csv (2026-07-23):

epoch | time | train/box_loss | train/cls_loss | train/dfl_loss | metrics/precision(B) | metrics/recall(B) | metrics/mAP50(B) | metrics/mAP50-95(B) | val/box_loss | val/cls_loss | val/dfl_loss | lr/pg0 | lr/pg1 | lr/pg2
1 | 3.07117 | 1.08984 | 4.03678 | 1.22043 | 0.00729 | 0.70076 | 0.05937 | 0.05492 | 0.5718 | 4.17734 | 0.91391 | 4.165e-05 | 4.165e-05 | 4.165e-05
2 | 4.48949 | 1.00379 | 3.90738 | 1.1377 | 0.01103 | 0.7904 | 0.17116 | 0.16254 | 0.56308 | 4.058 | 0.87544 | 8.98157e-05 | 8.98157e-05 | 8.98157e-05
3 | 5.86065 | 0.95979 | 3.65405 | 1.08433 | 0.01336 | 0.83586 | 0.20552 | 0.17832 | 0.58408 | 3.98196 | 0.83725 | 0.000136002 | 0.000136002 | 0.000136002
4 | 7.07781 | 0.9771 | 3.47061 | 1.09842 | 0.0168 | 0.9154 | 0.26116 | 0.22528 | 0.56909 | 3.96579 | 0.82831 | 0.00018021 | 0.00018021 | 0.00018021
5 | 8.27748 | 1.06216 | 3.34887 | 1.21854 | 0.01248 | 0.89268 | 0.24137 | 0.18541 | 0.6305 | 3.94272 | 0.86821 | 0.000222438 | 0.000222438 | 0.000222438
6 | 9.68716 | 1.03068 | 3.12363 | 1.15674 | 0.01107 | 0.89268 | 0.28368 | 0.24162 | 0.78411 | 3.87275 | 0.89648 | 0.000262687 | 0.000262687 | 0.000262687
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

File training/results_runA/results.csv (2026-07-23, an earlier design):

epoch | time | train/box_loss | train/cls_loss | train/dfl_loss | metrics/precision(B) | metrics/recall(B) | metrics/mAP50(B) | metrics/mAP50-95(B) | val/box_loss | val/cls_loss | val/dfl_loss | lr/pg0 | lr/pg1 | lr/pg2 | lr/pg3 | lr/pg4 | lr/pg5 | lr/pg6 | lr/pg7
1 | 242.67 | 0.56972 | 1.34318 | 0.95337 | 0.89933 | 0.85925 | 0.93509 | 0.86948 | 0.36599 | 0.61777 | 0.81382 | 0.00998208 | 0.00332736 | 0.00998208 | 0.00332736 | 0.00998208 | 0.00332736 | 0.00998208 | 0.00332736
2 | 479.378 | 0.57836 | 0.62018 | 0.95624 | 0.79979 | 0.69473 | 0.76476 | 0.69444 | 0.4291 | 1.05057 | 0.83981 | 0.0197348 | 0.00657827 | 0.0197348 | 0.00657827 | 0.0197348 | 0.00657827 | 0.0197348 | 0.00657827
3 | 711.657 | 0.63077 | 0.62229 | 0.9824 | 0.67159 | 0.56444 | 0.65329 | 0.55164 | 0.56255 | 1.12953 | 0.94186 | 0.02924 | 0.00974667 | 0.02924 | 0.00974667 | 0.02924 | 0.00974667 | 0.02924 | 0.00974667
4 | 945.57 | 0.60887 | 0.59057 | 0.97774 | 0.70917 | 0.60267 | 0.72426 | 0.64467 | 0.50252 | 1.12882 | 0.93013 | 0.0288862 | 0.00962875 | 0.0288862 | 0.00962875 | 0.0288862 | 0.00962875 | 0.0288862 | 0.00962875
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

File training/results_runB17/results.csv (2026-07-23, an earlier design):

epoch | time | train/box_loss | train/cls_loss | train/dfl_loss | metrics/precision(B) | metrics/recall(B) | metrics/mAP50(B) | metrics/mAP50-95(B) | val/box_loss | val/cls_loss | val/dfl_loss | lr/pg0 | lr/pg1 | lr/pg2 | lr/pg3 | lr/pg4 | lr/pg5 | lr/pg6 | lr/pg7
1 | 505.62 | 0.54774 | 1.99054 | 0.96772 | 0.61671 | 0.65256 | 0.66821 | 0.62101 | 0.32405 | 1.23547 | 0.81969 | 0.00998611 | 0.0033287 | 0.00998611 | 0.0033287 | 0.00998611 | 0.0033287 | 0.00998611 | 0.0033287
2 | 974.312 | 0.53858 | 1.00319 | 0.95309 | 0.61577 | 0.65973 | 0.6619 | 0.6054 | 0.36562 | 0.84061 | 0.84714 | 0.0196563 | 0.00655211 | 0.0196563 | 0.00655211 | 0.0196563 | 0.00655211 | 0.0196563 | 0.00655211
3 | 1446.91 | 0.56994 | 0.94282 | 0.97447 | 0.57804 | 0.56737 | 0.58674 | 0.5299 | 0.3926 | 1.10469 | 0.87153 | 0.0289966 | 0.00966552 | 0.0289966 | 0.00966552 | 0.0289966 | 0.00966552 | 0.0289966 | 0.00966552
4 | 1970.03 | 0.55294 | 0.89234 | 0.97223 | 0.59748 | 0.69023 | 0.65439 | 0.60473 | 0.33576 | 0.88037 | 0.83921 | 0.028515 | 0.009505 | 0.028515 | 0.009505 | 0.028515 | 0.009505 | 0.028515 | 0.009505
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

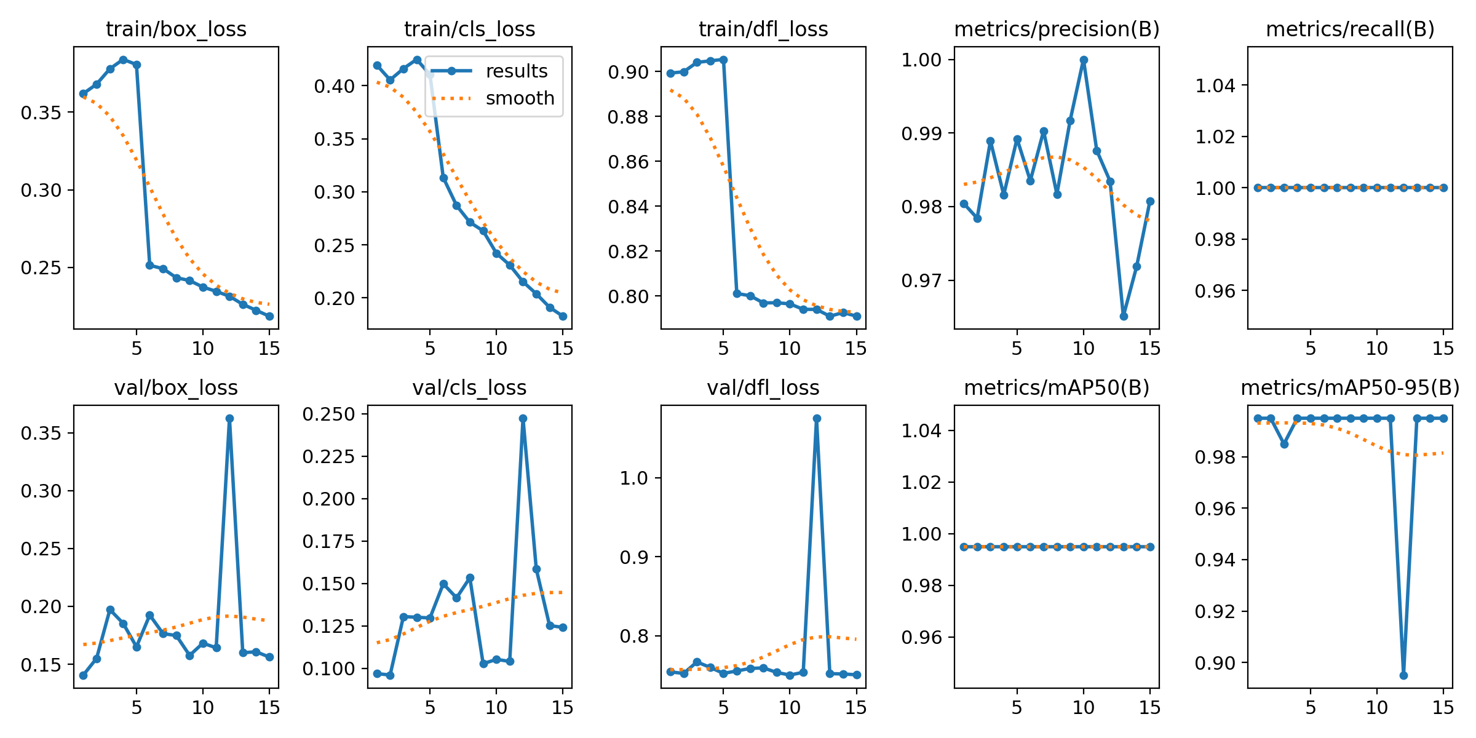
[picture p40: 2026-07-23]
docs/img/ft1_results_curves.png

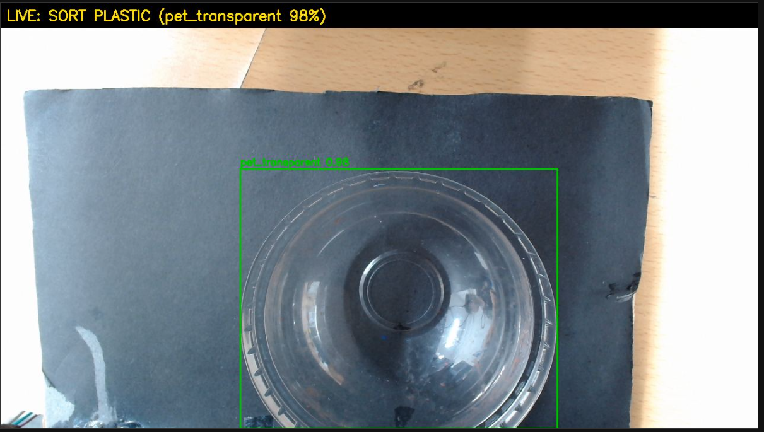
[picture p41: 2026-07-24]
docs/img/ft1_test_pet_domelid.png

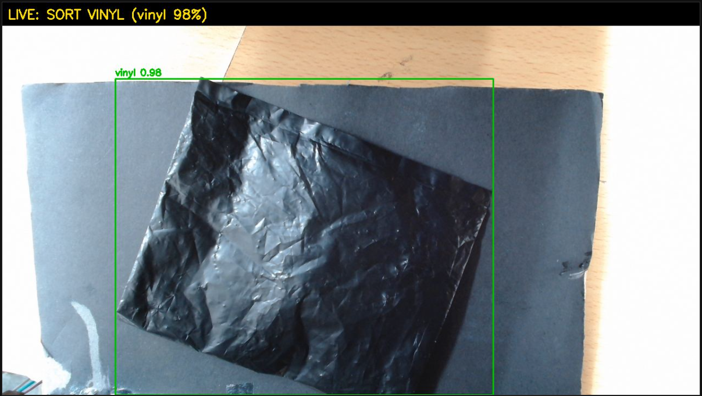
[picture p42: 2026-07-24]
docs/img/ft1_test_vinyl_black.png

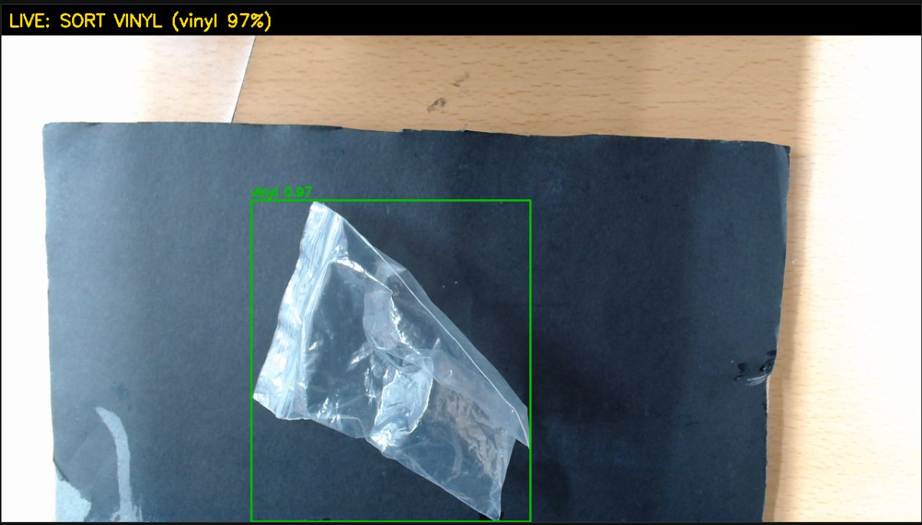
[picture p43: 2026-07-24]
docs/img/ft1_test_vinyl_clear.png

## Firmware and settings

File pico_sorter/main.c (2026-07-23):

// 분리수거 자동분류기 구동부 v2 — 캐러셀(수거함 회전) + 투입구 양문
//
// 기구 구조 (사진 참조 구조):
//   투입구 양문(서보1·3)에 물체가 놓임 → 촬영·판정 →
//   아래 수거함 회전판(서보2)이 해당 칸 각도로 회전 →
//   양문이 반대방향 동기로 열려 낙하 → 닫힘
//
// 배선:
//   서보1 (투입구 왼문)   → GP0 (물리핀 1)
//   서보2 (수거함 회전판) → GP1 (물리핀 2)
//   서보3 (투입구 오른문) → GP2 (물리핀 4)
//   HC-SR04              → TRIG=GP16, ECHO=GP17 (1k/2k 분압)
//   LCD1602 I2C          → SDA=GP4, SCL=GP5
//   서보 전원             → 별도 5~6V(건전지), GND 공통
//
// 시리얼 프로토콜 (상위 Jetson/노트북 ↔ Pico):
//   [수신] SORT PET|CAN|PLASTIC|ETC   회전판 정렬 → 양문 개방 → DONE
//          REJECT <사유>              양문 열지 않고 리턴 안내
//          READY / BUSY / PING / TEST
//   [수동/캘리브레이션]
//          open [양] / close          양문 직접 개폐
//          d1|d2|d3 <각도>            서보 개별 원시 각도
//          cfg [키 값]                설정 (c1 c3 amt b0 b1 b2 b3)
//   [송신] DETECT <cm> / CLEAR <cm> / DONE <칸> / PONG
#include <stdio.h>
#include <string.h>
#include <stdlib.h>
#include "pico/stdlib.h"
#include "hardware/pwm.h"
#include "hardware/i2c.h"

#define DOOR_L_PIN   0
#define CAROUSEL_PIN 1
#define DOOR_R_PIN   2
#define TRIG_PIN    16
#define ECHO_PIN    17
#define SDA_PIN      4
#define SCL_PIN      5

#define DETECT_CM 15.0f
#define CLEAR_CM  18.0f

// ── 조절 가능 설정 (cfg로 런타임 변경) ──
static int cfg_close_l = 90;                 // 왼문 닫힘
static int cfg_close_r = 90;                 // 오른문 닫힘
static int cfg_amount  = 60;                 // 문 열림 양 (왼 +, 오른 −)
static int cfg_bin[4]  = {0, 60, 120, 180};  // 칸별 회전판 각도
static const char *BIN_NAME[4] = {"PET", "CAN", "PLASTIC", "ETC"};

static int cur_l, cur_r, cur_car;
static int lcd_addr = 0;
#define LCD_BL 0x08

// ── 서보 ──
static void servo_init(uint pin) {
    gpio_set_function(pin, GPIO_FUNC_PWM);
    uint slice = pwm_gpio_to_slice_num(pin);
    pwm_set_clkdiv(slice, 150.0f);
    pwm_set_wrap(slice, 20000);
    pwm_set_enabled(slice, true);
}
static int clamp(int v) { return v < 0 ? 0 : (v > 180 ? 180 : v); }
static void servo_raw(uint pin, int deg) {
    pwm_set_gpio_level(pin, 500 + clamp(deg) * 2000 / 180);
}

/* 양문 동기 이동 — 1도씩 번갈아, 반대 방향이어도 같은 속도로 동시 도착 */
static void doors_move(int tl, int tr) {
    tl = clamp(tl); tr = clamp(tr);
    while (cur_l != tl || cur_r != tr) {
        if (cur_l != tl) { cur_l += (tl > cur_l) ? 1 : -1; servo_raw(DOOR_L_PIN, cur_l); }
        if (cur_r != tr) { cur_r += (tr > cur_r) ? 1 : -1; servo_raw(DOOR_R_PIN, cur_r); }
        sleep_ms(8);
    }
    sleep_ms(150);
}
static void doors_open(int amt) { doors_move(cfg_close_l + amt, cfg_close_r - amt); }
static void doors_close(void)   { doors_move(cfg_close_l, cfg_close_r); }

/* 회전판 — 수거함 무게 때문에 특히 천천히 (2도/24ms) */
static void carousel_move(int target) {
    target = clamp(target);
    while (cur_car != target) {
        int step = (target > cur_car) ? 2 : -2;
        cur_car += step;
        if ((step > 0 && cur_car > target) || (step < 0 && cur_car < target)) cur_car = target;
        servo_raw(CAROUSEL_PIN, cur_car);
        sleep_ms(24);
    }
    sleep_ms(400);   // 수거함 관성 정착 대기
}

// ── LCD (MAP A, 검증된 타이밍) ──
static void lcd_wr(uint8_t b) { i2c_write_blocking(i2c0, lcd_addr, &b, 1, false); }
static void lcd_nib(uint8_t nib, uint8_t rs) {
    uint8_t base = (nib & 0xF0) | LCD_BL | (rs ? 0x01 : 0);
    lcd_wr(base);        sleep_us(50);
    lcd_wr(base | 0x04); sleep_us(50);
    lcd_wr(base);        sleep_us(150);
}
static void lcd_byte(uint8_t v, uint8_t rs) {
    lcd_nib(v & 0xF0, rs); lcd_nib((v << 4) & 0xF0, rs); sleep_us(150);
}
static void lcd_init(void) {
    sleep_ms(60);
    lcd_nib(0x30, 0); sleep_ms(6);
    lcd_nib(0x30, 0); sleep_ms(6);
    lcd_nib(0x30, 0); sleep_ms(6);
    lcd_nib(0x20, 0); sleep_ms(6);
    lcd_byte(0x28, 0); sleep_ms(2);
    lcd_byte(0x08, 0); sleep_ms(2);
    lcd_byte(0x01, 0); sleep_ms(5);
    lcd_byte(0x06, 0); sleep_ms(2);
    lcd_byte(0x0C, 0); sleep_ms(2);
}
static void lcd_print(int line, const char *s) {
    if (!lcd_addr) return;
    lcd_byte(line == 0 ? 0x80 : 0xC0, 0);
    for (int i = 0; i < 16; i++) lcd_byte(i < (int)strlen(s) ? s[i] : ' ', 1);
}
static void lcd_show(const char *a, const char *b) { lcd_print(0, a); lcd_print(1, b); }

// ── 초음파 ──
static float measure_cm(void) {
    gpio_put(TRIG_PIN, 1); sleep_us(10); gpio_put(TRIG_PIN, 0);
    absolute_time_t dl = make_timeout_time_us(30000);
    while (!gpio_get(ECHO_PIN))
        if (absolute_time_diff_us(get_absolute_time(), dl) < 0) return -1;
    absolute_time_t st = get_absolute_time();
    while (gpio_get(ECHO_PIN))
        if (absolute_time_diff_us(get_absolute_time(), dl) < 0) return -1;
    return (float)absolute_time_diff_us(st, get_absolute_time()) / 58.0f;
}
static float median3(float a, float b, float c) {
    if ((a >= b && a <= c) || (a <= b && a >= c)) return a;
    if ((b >= a && b <= c) || (b <= a && b >= c)) return b;
    return c;
}

// ── 분배 시퀀스 ──
static void do_sort(int bin) {
    char buf[20];
    snprintf(buf, sizeof(buf), "-> %s", BIN_NAME[bin]);
    lcd_show("SORTING", buf);
    printf("분배: %s (회전판 %d도)\n", BIN_NAME[bin], cfg_bin[bin]);

    carousel_move(cfg_bin[bin]);   // 1) 수거함 정렬 (문 열기 전에!)
    doors_open(cfg_amount);        // 2) 양문 개방 → 낙하
    sleep_ms(900);
    doors_close();                 // 3) 양문 닫기

    lcd_show("DONE", buf);
    printf("DONE %s\n", BIN_NAME[bin]);
}

static void show_cfg(void) {
    printf("cfg: c1=%d c3=%d amt=%d | 칸각도 b0(PET)=%d b1(CAN)=%d b2(PLASTIC)=%d b3(ETC)=%d\n",
           cfg_close_l, cfg_close_r, cfg_amount, cfg_bin[0], cfg_bin[1], cfg_bin[2], cfg_bin[3]);
    printf("현재: 왼문=%d 오른문=%d 회전판=%d\n", cur_l, cur_r, cur_car);
}

static void run_cmd(char *line) {
    if (!strncmp(line, "SORT ", 5) || !strncmp(line, "sort ", 5)) {
        const char *w = line + 5;
        for (int i = 0; i < 4; i++)
            if (!strcasecmp(w, BIN_NAME[i])) { do_sort(i); return; }
        printf("알 수 없는 칸: %s\n", w);
    }
    else if (!strncasecmp(line, "REJECT", 6)) {
        lcd_show("RETURN", line[6] ? line + 7 : "");
        printf("리턴 안내 (양문 유지)\n");
    }
    else if (!strcasecmp(line, "READY")) { lcd_show("READY", "PUT ONE ITEM"); printf("대기\n"); }
    else if (!strcasecmp(line, "BUSY"))  { lcd_show("ANALYZING...", "PLEASE WAIT"); }
    else if (!strcasecmp(line, "PING"))  { printf("PONG\n"); }
    else if (!strcasecmp(line, "TEST")) {
        printf("자가 점검: 4칸 순회 + 양문 개폐\n");
        for (int i = 0; i < 4; i++) {
            char b[20]; snprintf(b, sizeof(b), "TEST %s", BIN_NAME[i]);
            lcd_show(b, "");
            carousel_move(cfg_bin[i]);
            doors_open(cfg_amount); sleep_ms(500);
            doors_close();          sleep_ms(300);
        }
        carousel_move(cfg_bin[0]);
        lcd_show("TEST DONE", "");
        printf("점검 완료\n");
    }
    // ── 수동/캘리브레이션 ──
    else if (!strncmp(line, "open", 4)) {
        int amt = (line[4] == ' ') ? atoi(line + 5) : cfg_amount;
        printf("양문 열기 %d (반대방향 동기)\n", amt);
        doors_open(amt); printf("완료\n");
    }
    else if (!strcmp(line, "close")) { doors_close(); printf("양문 닫힘\n"); }
    else if (!strncmp(line, "d1 ", 3)) { doors_move(atoi(line + 3), cur_r); printf("왼문=%d\n", cur_l); }
    else if (!strncmp(line, "d2 ", 3)) { carousel_move(atoi(line + 3)); printf("회전판=%d\n", cur_car); }
    else if (!strncmp(line, "d3 ", 3)) { doors_move(cur_l, atoi(line + 3)); printf("오른문=%d\n", cur_r); }
    else if (!strcmp(line, "cfg")) show_cfg();
    else if (!strncmp(line, "cfg ", 4)) {
        char key[8]; int v;
        if (sscanf(line + 4, "%7s %d", key, &v) == 2) {
            if (!strcmp(key, "c1")) cfg_close_l = clamp(v);
            else if (!strcmp(key, "c3")) cfg_close_r = clamp(v);
            else if (!strcmp(key, "amt")) cfg_amount = v;
            else if (key[0] == 'b' && key[1] >= '0' && key[1] <= '3' && !key[2])
                cfg_bin[key[1] - '0'] = clamp(v);
            else { printf("키: c1 c3 amt b0 b1 b2 b3\n"); return; }
            show_cfg();
        } else printf("사용법: cfg <키> <값>\n");
    }
    else if (!strcmp(line, "help")) {
        printf("SORT PET|CAN|PLASTIC|ETC / REJECT / READY / BUSY / TEST / PING\n");
        printf("open [양] / close / d1|d2|d3 <각> / cfg [키 값]\n");
    }
    else if (strlen(line)) printf("모르는 명령: %s\n", line);
}

int main(void) {
    stdio_init_all();

    servo_init(DOOR_L_PIN);
    servo_init(CAROUSEL_PIN);
    servo_init(DOOR_R_PIN);
    cur_l = cfg_close_l; cur_r = cfg_close_r; cur_car = cfg_bin[0];
    servo_raw(DOOR_L_PIN, cur_l);
    servo_raw(CAROUSEL_PIN, cur_car);
    servo_raw(DOOR_R_PIN, cur_r);

    gpio_init(TRIG_PIN); gpio_set_dir(TRIG_PIN, GPIO_OUT); gpio_put(TRIG_PIN, 0);
    gpio_init(ECHO_PIN); gpio_set_dir(ECHO_PIN, GPIO_IN);

    i2c_init(i2c0, 100 * 1000);
    gpio_set_function(SDA_PIN, GPIO_FUNC_I2C);
    gpio_set_function(SCL_PIN, GPIO_FUNC_I2C);
    gpio_pull_up(SDA_PIN);
    gpio_pull_up(SCL_PIN);

    sleep_ms(1500);
    for (int a = 0x08; a < 0x78 && !lcd_addr; a++) {
        uint8_t rx;
        if (i2c_read_timeout_us(i2c0, a, &rx, 1, false, 2000) >= 0) lcd_addr = a;
    }
    if (lcd_addr) { lcd_init(); lcd_show("SORTER READY", "PUT ONE ITEM"); }

    printf("\n=== 분류기 구동부 v2 (캐러셀+양문, LCD 0x%02X) ===\n", lcd_addr);
    show_cfg();

    char buf[64];
    int n = 0;
    bool detected = false;
    absolute_time_t next_scan = get_absolute_time();

    while (true) {
        int c = getchar_timeout_us(0);
        while (c != PICO_ERROR_TIMEOUT) {
            if (c == '\r' || c == '\n') {
                buf[n] = 0;
                if (n) { printf("\n"); run_cmd(buf); }
                n = 0;
            } else if ((c == 8 || c == 127) && n > 0) {
                n--; printf("\b \b");
            } else if (n < 63 && c >= 32) {
                buf[n++] = (char)c;
                putchar(c);   // 에코 (수동 조작 시 입력이 보이게)
            }
            c = getchar_timeout_us(0);
        }

        if (absolute_time_diff_us(get_absolute_time(), next_scan) < 0) {
            next_scan = make_timeout_time_ms(200);
            float d = median3(measure_cm(), measure_cm(), measure_cm());
            if (d > 0) {
                if (d < DETECT_CM && !detected) {
                    detected = true;
                    printf("DETECT %.1f\n", d);
                    lcd_show("DETECTED", "ANALYZING...");
                } else if (d >= CLEAR_CM && detected) {
                    detected = false;
                    printf("CLEAR %.1f\n", d);
                    lcd_show("READY", "PUT ONE ITEM");
                }
            }
        }
    }
}

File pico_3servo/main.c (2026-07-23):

// 서보 3개 테스트 — 투입구 양문(1·3번, 반대 방향 동기) + 셔터(2번)
//
// 배선:
//   서보1 (투입구 왼문)  신호 → GP0 (물리핀 1)
//   서보2 (셔터)         신호 → GP1 (물리핀 2)
//   서보3 (투입구 오른문) 신호 → GP2 (물리핀 4)   ← 새로 추가
//   전원: 3개 모두 별도 5~6V(건전지), GND 공통
//
// ★ 투입구 양문은 서로 마주보게 장착되므로, 같은 양만큼 열려면
//   왼문은 +방향, 오른문은 −방향으로 "반대로" 움직여야 한다.
//   open/close 명령이 이를 자동 처리하며, 두 문은 1도씩 번갈아
//   같은 속도로 동기 이동한다.
//
// 시리얼 명령 (115200, 엔터로 실행):
//   open [양]     투입구 열기 (기본 60도만큼, 양문 반대방향 동기)
//   close         투입구 닫기
//   shopen        셔터 열기 / shclose  셔터 닫기
//   d1 <0~180>    서보1 원시 각도 (캘리브레이션용 개별 제어)
//   d2 <0~180>    서보2(셔터) 원시 각도
//   d3 <0~180>    서보3 원시 각도
//   cfg           현재 설정 보기
//   cfg c1 <각>   왼문 닫힘 각도 설정   (기본 90)
//   cfg c3 <각>   오른문 닫힘 각도 설정 (기본 90)
//   cfg amt <각>  열림 양 설정          (기본 60)
//   cfg so <각>   셔터 열림 각도        (기본 100)
//   cfg sc <각>   셔터 닫힘 각도        (기본 10)
//   demo          전체 사이클 시연 (문 열기→닫기→셔터 열기→닫기)
//   help          명령 목록
#include <stdio.h>
#include <string.h>
#include <stdlib.h>
#include "pico/stdlib.h"
#include "hardware/pwm.h"

#define DOOR_L_PIN 0   // 서보1: 투입구 왼문
#define SHUTTER_PIN 1  // 서보2: 셔터
#define DOOR_R_PIN 2   // 서보3: 투입구 오른문

// ── 조절 가능한 설정 (cfg 명령으로 런타임 변경) ──
static int cfg_close_l = 90;   // 왼문 닫힘 각도
static int cfg_close_r = 90;   // 오른문 닫힘 각도
static int cfg_amount  = 60;   // 열림 양 (왼문 +, 오른문 −)
static int cfg_sh_open  = 100; // 셔터 열림
static int cfg_sh_close = 10;  // 셔터 닫힘

static int cur_l, cur_r, cur_sh;   // 현재 각도 추적

static void servo_init(uint pin) {
    gpio_set_function(pin, GPIO_FUNC_PWM);
    uint slice = pwm_gpio_to_slice_num(pin);
    pwm_set_clkdiv(slice, 150.0f);
    pwm_set_wrap(slice, 20000);
    pwm_set_enabled(slice, true);
}

static int clamp(int v) { return v < 0 ? 0 : (v > 180 ? 180 : v); }

static void servo_raw(uint pin, int deg) {
    pwm_set_gpio_level(pin, 500 + clamp(deg) * 2000 / 180);
}

/* 양문 동기 이동 — 두 문을 1도씩 번갈아 움직여 같은 속도 유지.
   목표: 왼문 tl, 오른문 tr. 서로 반대 방향이어도 동시에 도착한다. */
static void doors_move(int tl, int tr) {
    tl = clamp(tl); tr = clamp(tr);
    while (cur_l != tl || cur_r != tr) {
        if (cur_l != tl) { cur_l += (tl > cur_l) ? 1 : -1; servo_raw(DOOR_L_PIN, cur_l); }
        if (cur_r != tr) { cur_r += (tr > cur_r) ? 1 : -1; servo_raw(DOOR_R_PIN, cur_r); }
        sleep_ms(8);   // 1도당 8ms — 60도 이동에 약 0.5초
    }
    sleep_ms(150);
}

static void shutter_move(int t) {
    t = clamp(t);
    while (cur_sh != t) {
        cur_sh += (t > cur_sh) ? 1 : -1;
        servo_raw(SHUTTER_PIN, cur_sh);
        sleep_ms(6);
    }
    sleep_ms(150);
}

static void doors_open(int amt) {
    // ★ 반대 방향: 왼문은 닫힘각 + amt, 오른문은 닫힘각 − amt
    printf("투입구 열기: 왼문 %d→%d, 오른문 %d→%d (반대방향 동기)\n",
           cur_l, cfg_close_l + amt, cur_r, cfg_close_r - amt);
    doors_move(cfg_close_l + amt, cfg_close_r - amt);
    printf("열림 완료\n");
}

static void doors_close(void) {
    printf("투입구 닫기: 왼문 %d→%d, 오른문 %d→%d\n", cur_l, cfg_close_l, cur_r, cfg_close_r);
    doors_move(cfg_close_l, cfg_close_r);
    printf("닫힘 완료\n");
}

static void show_cfg(void) {
    printf("설정: 닫힘 c1=%d c3=%d / 열림양 amt=%d / 셔터 so=%d sc=%d\n",
           cfg_close_l, cfg_close_r, cfg_amount, cfg_sh_open, cfg_sh_close);
    printf("현재 각도: 왼문=%d 오른문=%d 셔터=%d\n", cur_l, cur_r, cur_sh);
}

static void cmd_help(void) {
    printf("명령: open [양] / close / shopen / shclose / d1|d2|d3 <각도>\n");
    printf("      cfg [c1|c3|amt|so|sc <각도>] / demo / help\n");
}

static void run_cmd(char *line) {
    if (!strcmp(line, "help")) cmd_help();
    else if (!strncmp(line, "open", 4)) {
        int amt = (line[4] == ' ') ? atoi(line + 5) : cfg_amount;
        doors_open(amt);
    }
    else if (!strcmp(line, "close")) doors_close();
    else if (!strcmp(line, "shopen"))  { printf("셔터 열기 → %d도\n", cfg_sh_open);  shutter_move(cfg_sh_open);  printf("완료\n"); }
    else if (!strcmp(line, "shclose")) { printf("셔터 닫기 → %d도\n", cfg_sh_close); shutter_move(cfg_sh_close); printf("완료\n"); }
    else if (!strncmp(line, "d1 ", 3)) { int a = atoi(line + 3); printf("서보1(왼문) → %d도\n", a); doors_move(a, cur_r); }
    else if (!strncmp(line, "d2 ", 3)) { int a = atoi(line + 3); printf("서보2(셔터) → %d도\n", a); shutter_move(a); }
    else if (!strncmp(line, "d3 ", 3)) { int a = atoi(line + 3); printf("서보3(오른문) → %d도\n", a); doors_move(cur_l, a); }
    else if (!strcmp(line, "cfg")) show_cfg();
    else if (!strncmp(line, "cfg ", 4)) {
        char key[8]; int v;
        if (sscanf(line + 4, "%7s %d", key, &v) == 2) {
            if (!strcmp(key, "c1")) cfg_close_l = clamp(v);
            else if (!strcmp(key, "c3")) cfg_close_r = clamp(v);
            else if (!strcmp(key, "amt")) cfg_amount = v;
            else if (!strcmp(key, "so")) cfg_sh_open = clamp(v);
            else if (!strcmp(key, "sc")) cfg_sh_close = clamp(v);
            else { printf("모르는 키: %s\n", key); return; }
            show_cfg();
        } else printf("사용법: cfg c1|c3|amt|so|sc <각도>\n");
    }
    else if (!strcmp(line, "demo")) {
        printf("=== 전체 사이클 시연 ===\n");
        doors_open(cfg_amount);  sleep_ms(700);
        doors_close();           sleep_ms(500);
        shutter_move(cfg_sh_open);  printf("셔터 열림\n"); sleep_ms(900);
        shutter_move(cfg_sh_close); printf("셔터 닫힘\n");
        printf("=== 시연 끝 ===\n");
    }
    else if (strlen(line)) printf("모르는 명령: %s (help 입력)\n", line);
}

int main(void) {
    stdio_init_all();

    servo_init(DOOR_L_PIN);
    servo_init(SHUTTER_PIN);
    servo_init(DOOR_R_PIN);
    cur_l = cfg_close_l;
    cur_r = cfg_close_r;
    cur_sh = cfg_sh_close;
    servo_raw(DOOR_L_PIN, cur_l);
    servo_raw(SHUTTER_PIN, cur_sh);
    servo_raw(DOOR_R_PIN, cur_r);

    sleep_ms(2500);
    printf("\n=== 서보 3개 테스트 (투입구 양문 + 셔터) ===\n");
    cmd_help();
    show_cfg();

    char buf[64];
    int n = 0;
    while (true) {
        int c = getchar_timeout_us(100000);
        if (c == PICO_ERROR_TIMEOUT) continue;
        if (c == '\r' || c == '\n') {
            printf("\n");
            buf[n] = 0;
            if (n) run_cmd(buf);
            n = 0;
            printf("> ");
        } else if ((c == 8 || c == 127) && n > 0) {
            n--; printf("\b \b");
        } else if (n < 63 && c >= 32) {
            buf[n++] = (char)c;
            putchar(c);
        }
    }
}

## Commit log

2026-07-23 recycling auto-sorter: full project (model training, edge deployment, firmware, docs)
    - YOLO11n 17-class training pipeline (AI Hub 71385), mAP50 0.912
    - Jetson Nano TensorRT bridge: 10-frame majority voting, systemd autostart
    - Pico 2 W state-machine firmware (sonar detect, servo carousel+door, LCD)
    - Laptop tools: browser bridge (WebSerial), fine-tune collector, live stream
    - Full docs: journal, design, class design, training report, wiring, portfolio
    [full_machine_concept.scad, results.csv]
2026-07-23 docs: add demo videos of assembled prototype + LCD stills
    - 4 demo clips (vinyl zipperbag, plastic dome lid) showing full cycle w/ LCD states
    - extracted presentation stills; journal & portfolio updated
2026-07-23 ft1 시연용 fine-tuning: 학습 결과·모델·문서 갱신 (자체 0.995/공식 0.880, 채택 보류)
    [results.csv]
2026-07-23 ft1 Jetson 배포: TensorRT FP16 엔진 전환(51.5ms), sorter.service 재기동 확인
2026-07-24 jetson_bridge: 카메라 늦은 인식/탈락 자동 복구 (열기 재시도 30회 + 런타임 재연결, 실패 시 systemd 재시작 유도)
2026-07-24 ft1 실물 검증 7/7 → 채택 확정: 오버레이 7종·카메라 자동복구 트러블슈팅 문서화
2026-07-27 docs: 발표자료 3차 수정본 작성 기록 (자체 평가형 개편·거짓 없는 수치 교정)
2026-07-27 wokwi: 최종 하드웨어 설계 반영한 회로도·시뮬레이션 (pico_sonar_test/wokwi로 이전)
    - 서보1 도어 GP0(닫힘90/열림180), 서보2 회전판 GP1(0/90/180 = PAPER/PLASTIC/VINYL)
    - HC-SR04 GP16/17(1k/2k 분압), LCD1602 I2C GP4/5
    - 서보 전원 별도 레일(VCC 심볼) + GND 공통 — 실물 건전지 분리 설계 반영
    - main.py를 실물 C 상태머신과 동일 로직으로 재작성, 구버전 pico_sorter/wokwi 제거
2026-07-27 docs: 최종 프로젝트 기술서 작성 기록
2026-07-27 docs: 발표문 작성·배경 서사 편의성 개편 기록
2026-07-27 docs: 회고형 포트폴리오 PDF 제작 기록
2026-07-27 docs: 포트폴리오 이미지 중심 개정판 기록
